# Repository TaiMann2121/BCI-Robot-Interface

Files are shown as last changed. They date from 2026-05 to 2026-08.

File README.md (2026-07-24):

# BCI Robot Interface

An integrated brain-computer interface (BCI) controlled robotic arm and hand system developed in the He Lab. BCI2000 decodes neural signals and streams control outputs to a Kinova Gen3 robotic arm and an Allegro Hand V4, enabling real-time robotic control from brain activity.

## System Overview

The piano task streams all control data as a single combined record on one
BCI2000 UDP port (5005) at 8 Hz. A dispatcher owns that port and fans the record
out to the two controllers:

```
BCI2000 (Windows)
  └── UDP 5005 → bci2000_dispatcher.py ┬── UDP 5006 → arm_controller.py → Kortex API → Kinova Gen3 Arm
                                        └── UDP 5007 → myAllegroHand.exe → PCAN-USB   → Allegro Hand V4
```

The keyboard is a 1-D layout of 11 keys (the middle 7 are notes C–B). The arm
slides horizontally along the keys to track `ArmPred_X`; the hand taps one of
three fingers (`CopilotFingerPred` = left/center/right) when `FingerMovePhase`
pulses. See [docs/setup_guide.md](docs/setup_guide.md) for the packet format and
calibration.

## Repository Structure

```
BCI_RobotInterface/
├── arm/                    Kinova Gen3 arm controller (Python)
├── hand/                   Allegro Hand V4 controller (C++ Visual Studio project)
├── dispatcher/            Single-port stream splitter (Python)
├── simulator/              Piano-stream simulator for testing without BCI2000
├── BCI2000 Piano/         Piano-task BCI2000 files (bat, prm, app module) for reference
└── docs/
    └── setup_guide.md      Full installation and configuration guide
```

## Getting Started

See [docs/setup_guide.md](docs/setup_guide.md) for complete setup instructions including hardware requirements, network configuration, software installation, and build steps.

For testing without BCI2000, run `dispatcher/bci2000_dispatcher.py` alongside
`simulator/bci_arm_hand_simulator.py` — the simulator replicates the real piano
stream (single port, 8 Hz, BCI2000 watch-packet framing) and lets you drive arm
positions and finger presses interactively.

For real experiments, launch BCI2000 with `BCI2000 Piano/SigGen_Piano_vel.bat`.

## Hardware

- Kinova Gen3 robotic arm (connected via Ethernet at `192.168.1.10`)
- Allegro Hand V4 — right hand configuration
- PEAK PCAN-USB CAN adapter

## Contact

He Lab — please reach out to the lab with any questions about this project.

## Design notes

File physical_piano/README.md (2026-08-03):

# Physical Piano — Start Here

Building a real 11-key piano to replace the toy playmat in the BCI arm/hand
piano task.

**Status:** design complete and verified against both the physical rig and the
switch datasheet. Nothing has been bought or fabricated yet.

## Layout

```
docs/       specifications and plans (Markdown — the source of truth)
share/      the same docs as .docx, for the shared Drive folder
cad/        OpenSCAD models
firmware/   Arduino sketch — key scanner only, makes no sound
pc/         computer-side listener that plays the notes
tools/      scripts that generate share/*.docx from docs/*.md
```

### Documents

| File | What it's for |
|---|---|
| [docs/SUPERVISOR_BRIEF.md](docs/SUPERVISOR_BRIEF.md) | **One page + the 4 decisions needed** — for the supervisor meeting |
| [docs/BUILD.md](docs/BUILD.md) | The spec: dimensions, sound, measured forces, mechanism |
| [docs/PURCHASING.md](docs/PURCHASING.md) | What to buy, with links and budget (~$457) |
| [docs/TECHSPARK_PLAN.md](docs/TECHSPARK_PLAN.md) | Fabrication plan + **parts manifest** |
| [docs/datasheets/](docs/datasheets/) | Kailh switch datasheet — the source for every switch dimension |

### CAD — four files, split by role

| File | Contains | Used by |
|---|---|---|
| [cad/piano_params.scad](cad/piano_params.scad) | **Single source of truth.** Every shared dimension and all sanity checks. Edit *here*. | everything |
| [cad/piano_keys.scad](cad/piano_keys.scad) | Key levers + black keys — **printed in both routes** | both |
| [cad/piano_base_printed.scad](cad/piano_base_printed.scad) | All-printed base (cells, 3 tiles) | route A |
| [cad/piano_base_laser.scad](cad/piano_base_laser.scad) | Laser base (2 sheets + stop rail) + 12 printed brackets | route B |
| [cad/piano_frame.scad](cad/piano_frame.scad) | Cosmetic surround — cheeks and rails. Purely aesthetic, print last | either |

> The two `base_*` files are **alternatives — build one, not both.** Either way
> you also need `piano_keys.scad`. Full breakdown in the TechSpark plan's parts
> manifest.

### Regenerating the .docx

```bash
node tools/md2docx.js docs/BUILD.md share/Physical_Piano_Build_Spec.docx
node tools/build_bom_docx.js          # the BOM, which has a custom layout
```

---

## What to do next, in order

### ① Right now (~1 hour, unblocks everything)

1. ~~Measure where the fingertips land on a key.~~ ✅ **35 mm from the front
   edge**, well inside the 53.2 mm clear zone — no black-key collision.
2. **Email TechSpark to book the consult** — Jen Hitchcock,
   jhitchco@andrew.cmu.edu. Lead time, so start early.
3. **Order the electronics** (~$100 — Arduino, MX switches, piezo, wire). They
   get bench-tested while the mechanical side is still in progress.

### ② Verify the CAD

4. Install [OpenSCAD](https://openscad.org) (free) and open each of the four
   `cad/*.scad` files. The console prints the derived geometry and will warn if
   anything is inconsistent. **Nothing has been rendered yet** — confirm the
   shapes look right before committing to fabrication.

### ③ TechSpark

5. Attend the consult — bring the questions in the TechSpark plan. The critical
   ones are laser bed size, 1.5 mm stock availability, and what laser time costs.
6. **Fabricate ONE key + base + black key and test it on the rig.** Do not batch
   11 until that passes.

### ④ Build

7. Full run: 11 keys, 7 black keys, and the base for whichever route was chosen.
8. Wire the 18 switches, flash the firmware, then run
   `python pc/piano_listener.py --port COMx`. Check audio first with
   `--test`, which needs no hardware.
9. Raise the arm ~5–8 mm so resting fingertips hover 2–5 mm above the key tops.
10. Re-run the demo sequence to validate.

---

## Two tracks run in parallel

- **Electronics** — breadboard the Arduino, switches and piezo; test the
  firmware and tuner with no mechanical parts at all.
- **Mechanical** — the slow track, gated by the TechSpark consult.

Start the electronics early so that half is proven before any key exists.

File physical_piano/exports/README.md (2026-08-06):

# Exports — generated files for TechSpark

**These are generated.** The source of truth is `../cad/*.scad`. They are
committed anyway so that a fresh `git clone` on any machine — a laptop taken to
the consult, or TechSpark's own PC — has everything needed to quote and cut,
without needing OpenSCAD installed first.

Regenerate any of them with:

```bash
openscad -o <output> -D 'mode="<mode>"' <source>.scad
```

Do not hand-edit anything here. If a dimension changes, change it in
`../cad/piano_params.scad` and re-export.

---

## Make these FIRST

| File | Process | Stock | Why |
|---|---|---|-----|
| `COUPON_print_switch_holes.stl` | FDM | PLA | 7 holes, 13.8–14.4 mm |
| `COUPON_laser_switch_holes_1.5mm.dxf` | laser | **1.5 mm** | same range, same stock as the real switch plate |

The switch datasheet specifies the plate cutout as 14.00 ±0.05 mm, which
neither process holds natively — FDM undersizes holes, laser kerf oversizes
them. Clip a real switch into each hole, take the smallest one it enters
without force and cannot be pulled out of, and set `mx_cut` from it.

Nothing else should be cut in quantity until that number is known.

---

## Laser route — 3 sheets

Sheet size is **565 × 174 mm** (this is the cut part; 545 mm is the keyboard
width alone, which is *not* the number to check a bed against).

| File | Stock | Qty |
|---|---|----:|
| `LASER_1_structure_9.0mm.dxf` | 9.0 mm | 1 |
| `LASER_2_switchplate_1.5mm.dxf` | **1.5 mm — mandatory**, this is what the MX clips grip | 1 |
| `LASER_3_stoprail_13.0mm.dxf` | 13.0 mm | 1 |
| `PRINT_hinge_bracket_x12.stl` | printed, not lasered | 12 |

The laser route also needs 6 × M3 12 mm standoffs (not yet ordered) and one
continuous 3 mm rod ≥ 581 mm.

## Printed route — 3 tiles

| File | Qty | Notes |
|---|----:|---|
| `PRINT_base_tile_0.stl` | 1 | cells 0–4, 250 mm |
| `PRINT_base_tile_1.stl` | 1 | cells 5–8, 200 mm |
| `PRINT_base_tile_2.stl` | 1 | cells 9–10, 100 mm |

The 5 + 4 + 2 split is not arbitrary — it is the only 3-way split that keeps
both seams off a black-key boundary, where a glue joint would run through a
switch's mounting hole.

## Both routes

| File | Qty | Notes |
|---|----:|---|
| `PRINT_key_lever_x11.stl` | 11 | **~20% infill — this is functional.** The switch guarantees only 15 gf of return force, so a key over 24 g presses its own switch and self-triggers. A solid print is ~41 g. |
| `PRINT_black_key_x7.stl` | 7 | |

---

## Not validated against hardware yet

These reflect the CAD as of the export date. `mx_cut` is still the datasheet
nominal, and two black-key dimensions (`mx_well_w`, `mx_shoulder_w`) are scaled
off a drawing rather than measured. See `../docs/BUILD.md` → "Open items".

Fine for quoting and for the coupon. **Not** to be run in quantity yet.

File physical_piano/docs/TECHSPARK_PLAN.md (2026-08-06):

# Plan for Working with CMU TechSpark

How we get the physical piano's mechanical parts made. Based on the TechSpark
services page: <https://engineering.cmu.edu/techspark/facilities/services.html>

---

## What TechSpark offers us

**3D printers**

| Printer | Process / material | Build volume | Min feature |
|---|---|---|---|
| Bambu X1C | FDM, PLA | 10 × 10 × 10″ (254 mm) | 0.4 mm |
| Stratasys F170 | FDM, ABS + **soluble support** | 10 × 10 × 10″ | 0.4 mm |
| Formlabs Form 3 | SLA resin (listed as coming soon) | 14.5 × 14.5 × 19.3 cm | 85 µm |

**Materials & pricing:** PLA **$0.64/g** · ABS **$1.03/g** · resin **$1.08/g**

**Also available:** machining, fabrication, welding, CNC, **laser cutting**, and
CAD/file-prep help from staff.
Professional services $65/hr + machining $72/hr or fabrication $74/hr.

**File formats accepted:** `.stl` `.obj` `.3mf` `.zip`

**How jobs are submitted:** through the **FBS system** at <https://cmu.fbs.io/>,
after an in-person consult at **Hamerschlag Hall C124**. Billing is via a CMU
oracle string / Andrew HUB account.

**Contacts**
- 3D printing & fabrication — **Jen Hitchcock**, jhitchco@andrew.cmu.edu
- Machining — **Ed Wojciechowski**, wojo@andrew.cmu.edu

---

## The one hard constraint this creates

**The keyboard is 545 mm wide; the build volume is 254 mm.** The keybed cannot
be printed as one piece. The CAD is already designed around this: the base is
built from **tileable 50 mm cells**, so we print it in runs and join them.

- 5 cells per tile = 250 mm → fits the 254 mm bed with 4 mm to spare.
- 11 keys = **3 tiles** (5 + 4 + 2 = cells 0-4, 5-8, 9-10), joined with M3
  hardware. The split is **not** free: the black keys' switch sockets straddle
  the white-key boundaries, so a seam must not land on one or the glue joint
  would run through the 14 mm hole the MX clips grip. Black keys sit after
  cells 0, 2, 3, 5, 6, 7 and 9, so only "after 4" and "after 8" are seam-safe,
  and with a 5-cell tile limit that is the only 3-way split that works.
  (5 + 5 + 1 put a seam after cell 9, which *is* a black-key boundary.)
- Individual white keys (140 × 45 mm) and black keys (87 × 26 mm) fit easily and
  can be batched many-per-plate.

---

## Proposed plan

### Phase 1 — Consult (before printing anything)
Go to **HH C124** and talk to Jen Hitchcock. Bring the CAD and these questions:

1. **Tolerances for moving parts.** There are exactly two moving fits in this
   design, and both are **0.4 mm** — which is also the X1C's stated *minimum
   feature*, so we are sitting on the machine's limit with no margin:

   - **Key side to hinge post, 0.4 mm gap.** The key pivots between two fixed
     posts standing in the 5 mm inter-key gap. Too tight and it rubs or jams
     through its swing; too loose and it wanders sideways on the pin.
   - **Pin bore to rod, 3.4 mm bore on a 3 mm rod.** 0.2 mm all round. This is
     the actual bearing — it is what lets the key rotate without slop.

   Ask: is 0.4 mm realistic in PLA on the X1C, or should we open it up? If the
   answer is open it up, that is a one-line change to `clr` / `pin_d` in
   `piano_params.scad` and a re-export, not a redesign.

   Worth asking in the same breath: the printed hinge post is a **2 mm thick
   fin, 25 mm tall, with a 3.4 mm hole through it** — a 12:1 aspect ratio in
   the thin direction. Will it print without warping or snapping? It is the
   most fragile part of the printed route.

   *(This is the most important question after the 1.5 mm stock one — the whole
   mechanism depends on the key pivoting freely without slop.)*

   > Earlier revisions of this list said "a pin hinge and a **sliding plunger**
   > with 0.4 mm clearances". The plunger slides in nothing: it is a free
   > standing 4 mm post that presses on the switch stem, with 6.5 mm of air
   > either side of it. That wording dated from a design where it ran in a
   > guide bore, and describing it that way at the consult would get advice
   > about a part that does not exist.
2. **PLA vs. ABS.** PLA is cheapest. The F170's **soluble support** could print
   the hinge better. Is ABS worth the 1.6× material cost here?
3. **Laser-cut the switch plate instead of printing tiles.** ⭐ *Highest-value
   question.* MX switches are plate-mount: they clip into a flat plate with
   14 × 14 mm square holes. Cutting that as **one piece** would:
   - hold all 11 switches at an exact **50 mm pitch with no tile seams** — the
     arm's calibration depends on that pitch, so this removes a real risk, not
     just a cost;
   - likely fit the laser bed in one piece where the 254 mm print bed cannot —
     but note the SHEET is **565 x 174 mm**, not 545. 545 is the keyboard width;
     the cut part adds a 10 mm side margin so the outermost hinge brackets land
     on material. Ask about 565, or a yes here becomes a no later;
   - reduce printed mass from ~502 g to ~275 g (**$321 → ~$176**). Note the
     saving is *modest*, not half: laser machine time is billed hourly and
     isn't quoted on the services page, so net saving is likely **$30–80**.
     **Ask what laser time actually costs** — it decides whether the cost
     argument holds at all. The pitch accuracy above is the real reason.

   A worked layered design already exists at
   [`../cad/piano_base_laser.scad`](../cad/piano_base_laser.scad): **three** flat
   layers — structure **9.0 mm**, switch plate **1.5 mm**, stop rail
   **13.0 mm** — whose thicknesses land the switch plate top at **z = 10.5 mm**
   and the stop top at **z = 23.5 mm**, identical to the printed route, so key
   height and arm height are unchanged either way. Only **12** small hinge
   brackets stay printed, because they need a cross-drilled pin hole a laser
   cannot make. (An earlier version had a fourth "spacer" layer and 22
   brackets; the spacer had no remaining job once the structural layer was
   drilled through under every switch, and there is one bracket per key
   boundary, which is 12.)

   Specifics to confirm: **can the bed take 565 x 174 mm**, and can they supply
   **1.5 mm stock** (the thickness MX switches clip into — this one is
   mandatory, not a preference) plus 9.0 mm and 13.0 mm? If 1.5 mm is too
   flimsy over that span, is a stepped two-layer plate (1.5 mm with 14 mm holes
   over a thicker backing with clearance holes) feasible?

   Also ask about **kerf compensation**: the switch cutout is specified
   14.00 ±0.05 mm and an uncompensated cut comes out ~0.2 mm oversize, which is
   the difference between a switch that clips and one that rattles. See the
   test-coupon step in BUILD.md.
4. **Tile joining.** The base cells carry alignment dowel half-holes at the
   two tile seams, so a seam closes onto a 3 mm rod rather than being butted
   by eye. Worth asking whether they would also glue or pin the seam, since
   the 50 mm key pitch — what the arm is calibrated to — has to survive two
   joins on this route. **This is now the likely route**, so it deserves more
   attention than the laser alternative.
5. Turnaround time and how billing works against our lab's oracle string.

### Phase 2 — Prototype ONE key

**Before this:** cut a hole-size coupon and set `mx_cut` from it, and put
calipers on a real switch for `mx_well_w` / `mx_shoulder_w`. Both are in
BUILD.md → "Open items". A switch that will not clip in makes every other
question on this list unanswerable.

Print **1 white key + 1 base cell + 1 black key** (~$30 of material) —
`mode = "assembly"` in `piano_base_printed.scad` is exactly that trio — and
check:

- Does the switch clip into the plate and stay there when pulled by hand?
- Does the key pivot freely and return cleanly?
- Does the switch actuate before the cap hits the bottom stops?
- Does the cap land on the **stop shoulders**, not on the switch? (Press hard —
  the whole point is that the frame takes the robot's overshoot.)
- Does the black keycap grip its cross, and travel its full 3.6 mm without
  fouling the switch housing?
- Do the robot's fingers land in the **front clear zone** (see below)?
- Is the key-top height reachable by the arm's vertical adjustment?

**Do not batch 11 until this passes.** Tuning a parameter costs one reprint at
this stage and eleven reprints later.

### Phase 3 — Full run
Once the prototype is signed off, submit:
- 11 × white key lever
- 3 × base tile (5 + 4 + 2 cells, with black-key switch sockets at the right
  boundaries)
  *— or the laser-cut plate stack, if consult question 3 is a yes*
- 7 × black key

> ⚠️ **Specify low infill (~20%) on the key levers.** This is a functional
> requirement with a hard number: the switch datasheet guarantees only **15 gf**
> of return force, so the **maximum safe key mass is 24 g**. A near-solid key at
> ~41 g would press its own switch and self-trigger. At ~20% infill (~16 g) there
> is a 1.5× margin. It is also cheaper, since TechSpark bills by the gram.

### Phase 4 — Assembly & integration
Wire the switches to the Arduino, flash the firmware, tune the tones, then set
the arm height so the resting fingertips hover 2–5 mm above the key tops, and
re-run the demo sequence.

---

## Parts manifest — what is made how

> ⚠️ **The CAD files are split by ROUTE, not by process.** `piano_base_laser.scad`
> is the laser *route* — it still contains one 3D-printed part. And **either route
> needs `piano_keys.scad`**, because the key levers and black keys are printed in
> both. Do not hand over a single file and assume it covers everything.

**Route A — all 3D printed**

| Part | File | `mode` | Process | Qty |
|---|---|---|---|----:|
| Key lever (notched for the black keys) | `piano_keys.scad` | `"key"` | print, PLA ~20% infill | 11 |
| Black key (switched keycap) | `piano_keys.scad` | `"black"` | print | 7 |
| Base tile | `piano_base_printed.scad` | `"tile"`, `tile_i` = 0/1/2 | print | 3 (5+4+2) |
| Frame cheek | `piano_frame.scad` | `"cheek"` | print | 2 |
| Frame front rail segment | `piano_frame.scad` | `"front_seg"` | print | 3 |
| Frame back rail segment | `piano_frame.scad` | `"back_seg"` | print | 3 |
| Hinge pin | — | — | buy 3 mm rod, cut | — |
| Tile alignment dowels | — | — | same 3 mm rod, 4 short pieces | — |

`mx_switch.scad` is **not a part**. It is a to-scale model of the Kailh switch
plus fit checks that place it in the board, so switch clearances can be looked
at instead of argued from numbers. Run its `"white"`, `"black"` and
`"fit_slice"` modes after any change to the socket, stop or keycap geometry.

Feet are printed into every base cell, so this route needs **no standoffs**.

**Route B — laser-cut base** *(the one we're asking about)*

| Part | File | `mode` | Process | Qty |
|---|---|---|---|----:|
| Key lever | `piano_keys.scad` | `"key"` | **print** | 11 |
| Black key | `piano_keys.scad` | `"black"` | **print** | 7 |
| Structure sheet | `piano_base_laser.scad` | `"2d_struct"` | **laser, 9 mm** | 1 |
| Switch plate | `piano_base_laser.scad` | `"2d_switch_plate"` | **laser, 1.5 mm** | 1 |
| Stop rail | `piano_base_laser.scad` | `"2d_stop_rail"` | **laser, 13 mm** | 1 |
| Hinge bracket | `piano_base_laser.scad` | `"hinge_block"` | **print** | 12 |
| Hinge pin | — | — | buy 3 mm rod, ~570 mm | 1 |
| Standoffs | — | — | buy, 12 mm M3 | 6 |

So Route B is **3 laser parts + 30 printed parts**, drawn from **two** files.

## What to send them

- **Laser:** `../cad/piano_base_laser.scad` exported to **DXF** — one file per `2d_*`
  mode (3 files), each tagged with its stock thickness.
- **Print:** STL per part — key lever and black key (`piano_keys.scad`), plus
  either the base tiles (`piano_base_printed.scad`)
  or the hinge bracket (`piano_base_laser.scad`).
- This document, for the manifest, build volumes, and material context.

*OpenSCAD is installed on the lab PC. Open any `cad/*.scad` file, set `mode`,
press F6, then File > Export. TechSpark staff can help with file prep as part of
professional services if needed.*

---

## Design status

✅ **Black-key clearance — resolved.** Black keys occupy the rear 62% of each
key, so fingers must press in the front 53.2 mm. Measured on the rig: the
fingertip lands **35 mm** from the front edge. Comfortably clear, no
repositioning needed.

⏳ **Base construction — still a choice, no longer a rework.** BOTH routes are
now fully modelled: `piano_base_printed.scad` (3 tiles, 5 + 4 + 2 cells) and
`piano_base_laser.scad` (3 flat layers + 12 printed brackets). Picking one is a
decision, not a redesign. The laser route cuts all 11 switch positions in ONE
operation, so the 50 mm pitch the arm is calibrated to has no glued seams to
drift across, and it is far cheaper in material; the printed route needs no
laser. **Confirm laser access and 9.0 / 1.5 / 13.0 mm stock before committing.**
They are alternatives — do not build both.

⏳ **Switch fit — not yet verified against hardware.** Every dimension the CAD
takes from the switch datasheet has been checked line by line, but three things
cannot be settled on paper: whether the switch actually purchased matches the
datasheet, the two stem dimensions the datasheet draws without dimensioning, and
whether the fabrication process holds the 14.00 ±0.05 plate cutout. See
BUILD.md → "Open items". **Nothing should be fabricated in quantity until these
close.**

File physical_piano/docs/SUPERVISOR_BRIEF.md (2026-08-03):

# Physical Piano — Status & Decisions Needed

One-page summary of the physical 11-key piano that replaces the toy playmat in
the BCI arm/hand piano task. Full detail is in the accompanying Build Spec,
Parts to Purchase, and TechSpark Plan documents.

---

## Your three asks — done

| Ask | Status |
|-----|---|
| **Add the black keys** | ✅ 7 black keys added, mirroring the simulator's exact proportions and positions. Decorative (no switches) as agreed. |
| **Links for materials to purchase** | ✅ Full list with links and prices → *Parts to Purchase* |
| **Plan for the machine shop** | ✅ Phased plan built from TechSpark's services page → *TechSpark Plan* |

## Design is complete — every dimension measured on the real rig

| Parameter | Value |
|---|---|
| Keys | 11 white (4.5 × 14 cm) + 7 black, 5.0 cm pitch, 54.5 cm total |
| Switches | MX-style linear, 45 gf actuation |
| Sound | Arduino tones, tunable from a computer, saved to the board |
| Switch spec | Verified against the Kailh datasheet — travel, forces, and clearances all check out |
| Robot press force | 362 / 500 / 520 gf (index / middle / ring) |
| Finger contact point | 35 mm from key front edge — clear of the black keys ✅ |

Firmware and the computer-side tuning tool are already written. Nothing in the
design is now a guess.

---

## What I need from you

### 1. Budget approval
| Option | Cost |
|---|-----:|
| All 3D printed | **~$457** |
| With a laser-cut base (see #2) | **~$295 + laser machine time** |

Electronics are only ~$100 of either. I'd like to order those **now** so I can
build and test the whole sound system on a breadboard while the mechanical parts
are still being made — the two halves are independent.

### 2. Laser-cut the base instead of 3D printing it?
I'd like to ask TechSpark about this. **The reason is accuracy, not cost.** The
keybed needs 11 switch holes at an exact 50 mm pitch, which is what the robot
arm is calibrated to. 3D printing means joining 3 separate tiles (the printers
are only 10″ wide), so the pitch has to survive two seams. Laser-cutting the
plate as one piece removes that risk entirely — and it's how these switches are
normally mounted.

I've drafted the layered version so both options are costed on the same basis.
On money it's a **modest** win, not a dramatic one: printed mass drops from
~502 g to ~275 g, but laser machine time is billed hourly and isn't published,
so the net saving is probably $40–90. I'll get a real number at the consult.

### 3. Funding account
TechSpark bills to a CMU oracle string. Which account should I use, and should I
place the material orders myself or send them to you?

### 4. Confirm the sound is what you pictured
You asked for electronic sound tunable on a computer, which is what I built: I
can set **each key's pitch** live over USB and save it. But the tone is always a
square-wave "beep" — the *timbre* can't be reshaped from the computer. If you
pictured adjusting the character of the sound (or wanted realistic piano
samples), that's a different setup and I'd rather find out now than after the
board is built.

---

## Two findings worth knowing

- **The arm needs to rise slightly.** The finished keyboard stands on 12 mm
  feet so the switch pins and wiring clear the desk, putting the key tops
  42.5 mm above the table. The fingers currently rest at 40 mm, so the arm
  goes up about 5–8 mm. Well within its adjustment range.
- **Keys must be printed at low infill — there's a hard limit.** The switch
  datasheet guarantees only 15 gf of return force, so a key must weigh under
  **24 g**. Ours is ~16 g at normal infill; printed near-solid it would be ~41 g
  and would sag onto its own switch and self-trigger. Cheaper too, since
  TechSpark bills by the gram.

## Next steps once approved

1. Book the TechSpark consult (Jen Hitchcock) — has lead time, so I'd start now
2. Order the electronics (~$100) and bench-test the sound
3. **Print one key and test it on the robot** before committing to all 11
4. Full print run → assemble → re-run the demo on the real keyboard

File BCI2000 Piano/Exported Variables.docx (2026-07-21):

CurrentTrial - block number 1-5

InnerTrialCount - trial number 0-

ArmPred_X - real-time robotic arm position with an offset of 32767; value should be within [-420, 420]

FingerMovePhase - indicate the timing of the finger motion; finger move when value turns True

CopilotFingerPred - finger prediction; 0, 1, 2

targetKeyIndex - target key [2, 8]

pressedKeyIndex - pressed key [0, 10]

ArmCurrentIndex - reflect the current arm position in terms of the key index (which key the middle finger is on) [1, 9]

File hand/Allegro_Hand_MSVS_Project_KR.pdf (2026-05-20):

# Allegro Hand Programming Tutorial

# Allegro Hand Console Application

# Allegro Hand 2.0

Copyright 2013 SimLab Co., Ltd. All rights reserved.

# - Creating a new project

# - CAN implementation

# - Monitoring joint angles using rPanelManipulator

# - Control Allegro Hand using BHand library

# - Source code

# ■ Creating a new project

1. Visual Studio 2008 실행한다.
2. “File > New > Project” 메뉴를 이용하여 새 프로젝트를 생성한다.
3. Win32 Console Application을 선택하고 프로젝트 이름에 myAllegroHand 라고 입력한다.

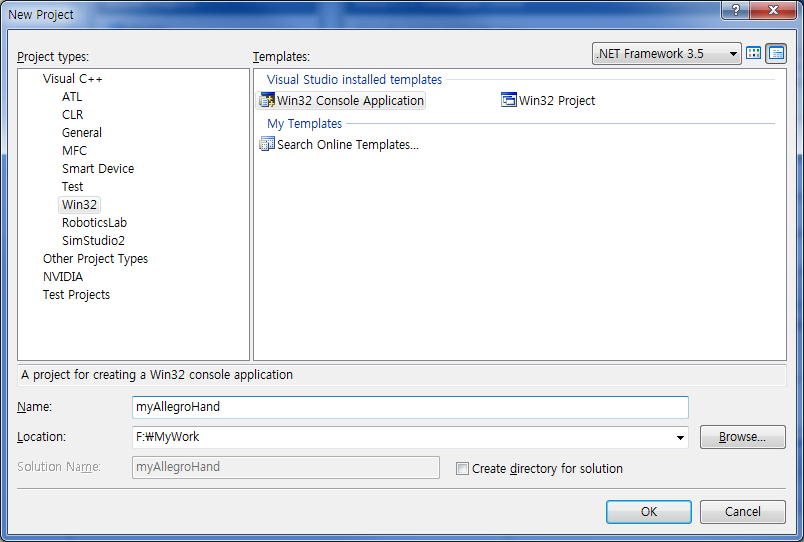
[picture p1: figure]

4. Application type에 “Console application”을 선택한 후 “Finish” 버튼을 눌러 완료한다.

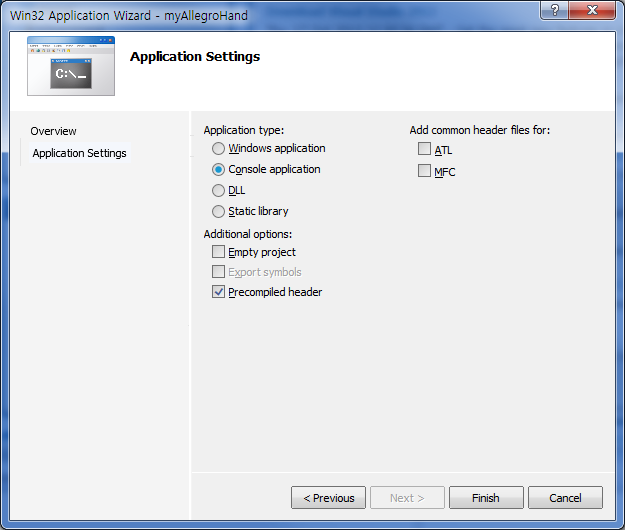
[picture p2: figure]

# 5. 프로젝트가 정상적으로 생성되었다면 CAN 통신 등을 위해 미리 작성된 파일들을 프로젝트가

# 생성된 폴더에 덮어쓴다. 그리고 프로젝트에 필요한 파일들을 추가한다. 다음은 필요 파일들을

추가한 후 솔루션 탐색기 모습이다. 프로젝트 생성시 자동 생성된 “stdafx.h”, “targetver.h”, “myAllegroHand.cpp”, “sdafx.cpp”, “ReadMe.txt” 외에 “canAPI.h”, “canDef.h”, PCANBasic.h”,

# “rDeviceAllegroHandCANDef.h”, “canAPI.cpp” 파일이 추가되어있다. 이 때 한가지 주의해야 할 점

# 은 CAN 장치 제조사마다 “canAPI.cpp” 파일을 같은 이름으로 하나씩 제공하고 있기 때문에 사

# 용하려고 하는 CAN 장치에 따라 알맞은 파일을 선택해야 한다는 것이다. 본 튜토리얼은 Peak

CAN | 장치를 | 사용하는 | 것을 | 가정하고 | 있다. | 때문에 | “canAPI.cpp” | 파일 | 추가시
“src\Peak\canAPI.cpp” 파일을 선택하여 프로젝트에 추가하였다.

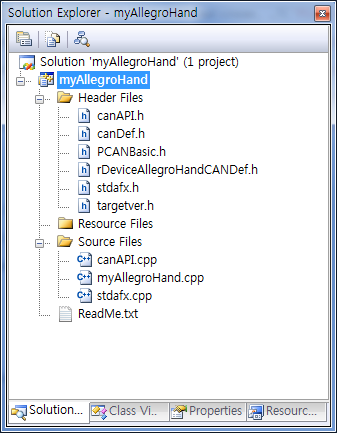
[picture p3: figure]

# 6. 프로젝트 설정 다이얼로그를 열기 위해 솔루션 탐색기에서 프로젝트를 선택한 후 마우스 우클

# 릭, 그리고 속성 메뉴를 선택한다. 프로젝트 설정 다이얼로그에서 다음과 같이 “Create/Use

Precompiled Header” 속성을 “Not Using Precompiled Headers”로 변경한다.

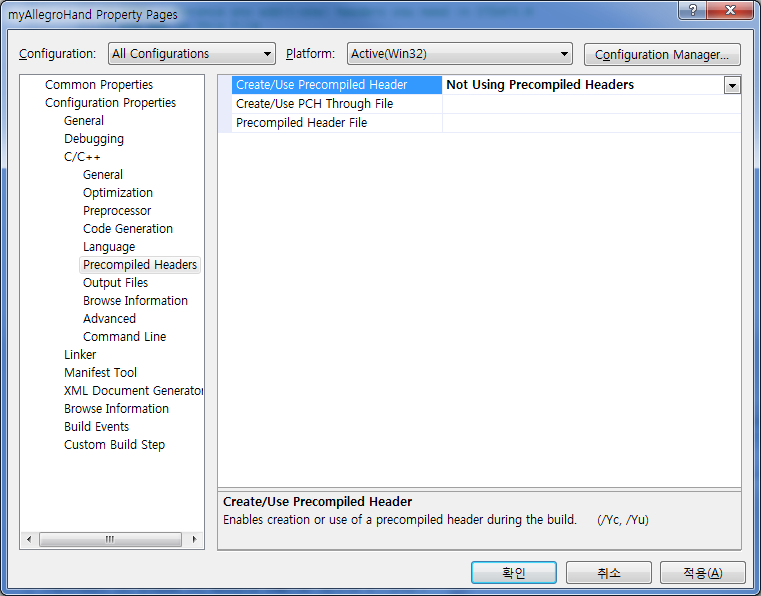
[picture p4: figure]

7. “Additional Include Directories”에 “include”를 추가한다.

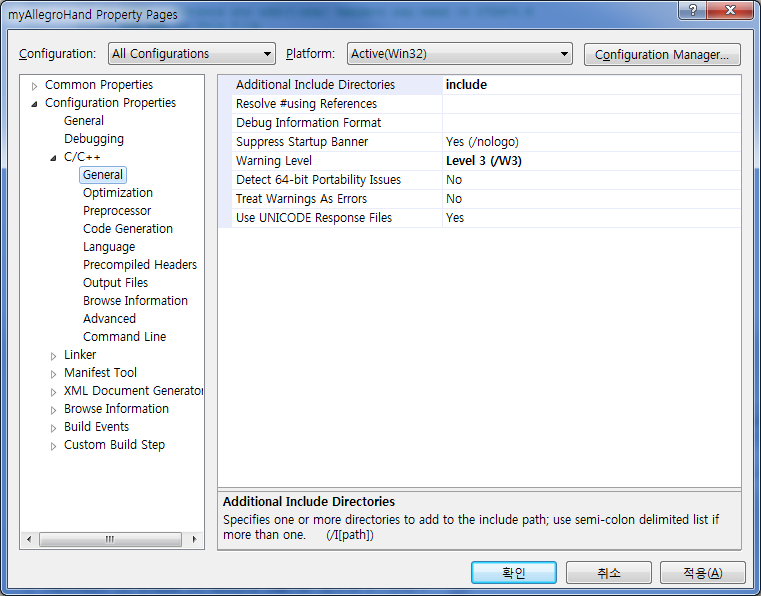
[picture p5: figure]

# 8. “Additional Library Directories”에 “lib\Peak”를 추가한다. 본 튜토리얼은 Peak CAN 장치를 이용

# 하는 것을 가정하고 있다. 만약 Peak CAN 이외의 다른 CAN 장치를 이용하는 경우 lib 폴더에서

# 해당 장치 제조사 이름의 폴더를 찾아 그 이름을 설정하도록 한다. 현재 Allegro Hand는 “ESD-

CAN”, “Kvaser”, “NI-CAN”, “Peak”, “Softing” CAN 장치를 지원한다.

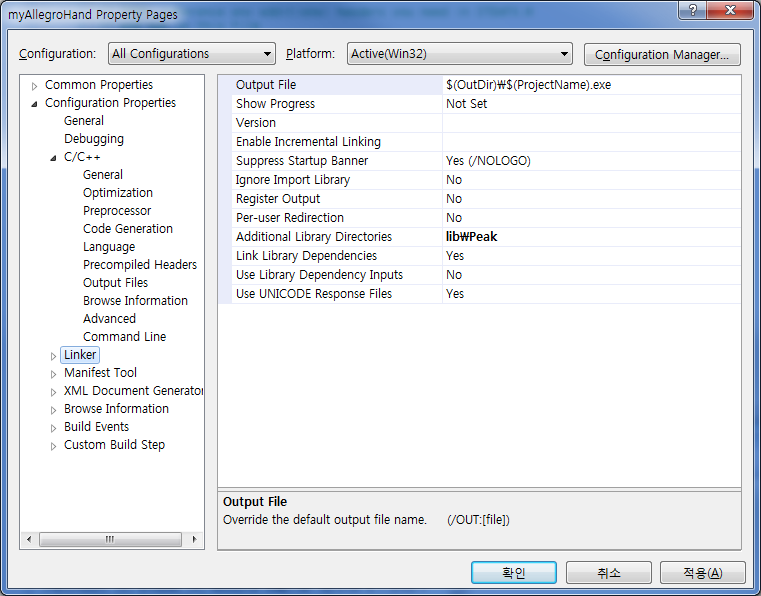
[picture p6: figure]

9. “Additional Dependancies”에 “PCANBasic.lib”을 추가한다.

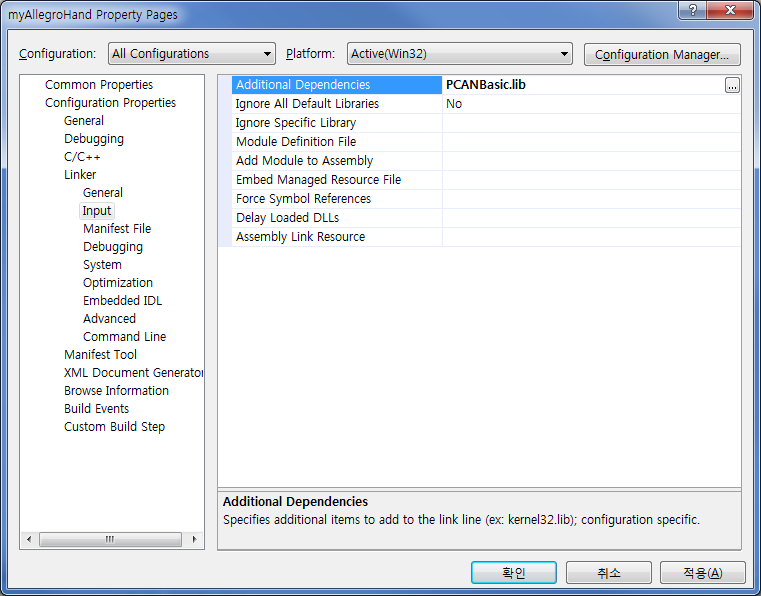
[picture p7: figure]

10. 실행 경로를 “bin”으로 설정한다.

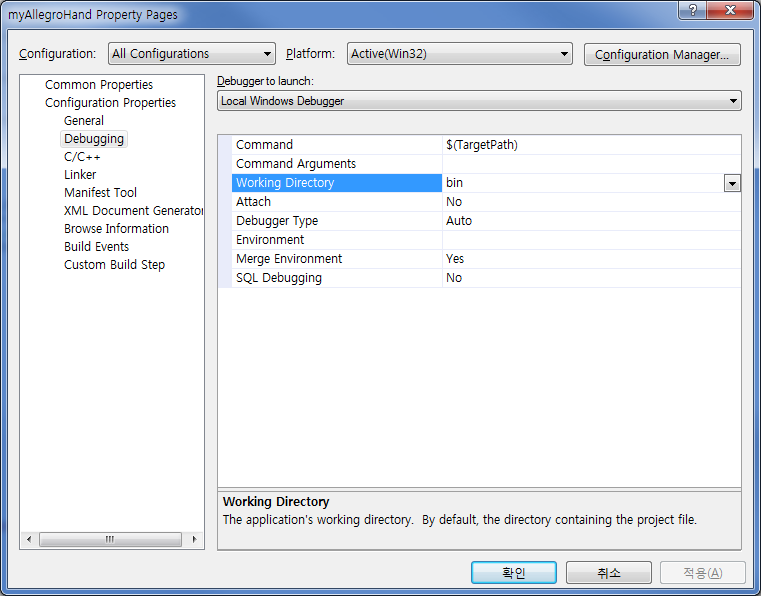
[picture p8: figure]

# ■ CAN implementation

11. 이제 myAllegroHand.cpp 파일을 연다. 먼저 필요한 헤더 파일을 추가한다.

#include "stdafx.h"

#include "windows.h"

#include <conio.h>

#include <process.h>

#include <tchar.h>

#include "canAPI.h"

#include "rDeviceAllegroHandCANDef.h"

# 12. CAN 통신을 위한 전역변수를 선언한다. “CAN_Ch” 변수는 CAN 통신 채널을 위한 인덱스를 저

# 장하기 위한 변수이다. “vars” 변수는 CAN 통신을 통해 수신된 각 관절 엔코더값 및 각 관절에

인가할 토크 명령을 저장한다.

int CAN_Ch = 0;
bool ioThreadRun = false;
uintptr_t ioThread = 0;
int recvNum = 0;
int sendNum = 0;
double statTime = -1.0;
double curTime = 0.0;
AllegroHand_DeviceMemory_t vars;

# 13. “main” 함수를 다음과 같이 편집한다. Main 함수는 크게 네가지 함수로 구성된다. 다음에 각 함

수에 대해 설명한다.

int _tmain(int argc, _TCHAR* argv[])
{
PrintInstruction();

if (OpenCAN())
{
MainLoop();
CloseCAN();
}

return 0;
};

# 14. “PrintInstruction()” 함수는 프로그램 정보 및 실행 방법 등을 콘솔에 출력하는 함수이다. 구현은

다음과 같다.

void PrintInstruction()
{
printf("--------------------------------------------------\n"); printf("myAllegroHand\n");
printf("\n");
printf("To quit this program, press 'q'.\n");
printf("--------------------------------------------------\n");
}

# 15. “OpenCAN()” 함수는 CAN 통신을 초기화하고 CAN을 통해 데이터 수신 및 송신을 위한 별도의

# 쓰레드(thread)를 생성한다. 그리고 Allegro Hand 시스템을 초기화하고 제어를 위해 주기적 통신

을 시작한다.

bool OpenCAN()
{
int ret;

CAN_Ch = GetCANChannelIndex(_T("USBBUS1"));

printf(">CAN(%d): open\n", CAN_Ch);
ret = command_can_open(CAN_Ch);
if(ret < 0)
{
printf("ERROR command_canopen !!! \n"); return false;
}

memset(&vars, 0, sizeof(vars)); recvNum = 0;
sendNum = 0;
statTime = 0.0;

ioThreadRun = true;
ioThread = _beginthreadex(NULL, 0, ioThreadProc, NULL, 0, NULL); printf(">CAN: starts listening CAN frames\n");

printf(">CAN: system init\n");
ret = command_can_sys_init(CAN_Ch, 3/*msec*/); if(ret < 0)
{
printf("ERROR command_can_sys_init !!! \n"); command_can_close(CAN_Ch);
return false;
}

printf(">CAN: start periodic communication\n"); ret = command_can_start(CAN_Ch);
if(ret < 0)
{
printf("ERROR command_can_start !!! \n"); command_can_stop(CAN_Ch);
command_can_close(CAN_Ch);
return false;
}

return true;
}
16. “CloseCAN()” 함수는 통신 쓰레드 및 CAN 통신을 종료한다.

void CloseCAN()
{
int ret;

printf(">CAN: stop periodic communication\n"); ret = command_can_stop(CAN_Ch);
if(ret < 0)
{
printf("ERROR command_can_stop !!! \n"); }

printf(">CAN: stoped listening CAN frames\n"); ioThreadRun = false;
WaitForSingleObject((HANDLE)ioThread, INFINITE); CloseHandle((HANDLE)ioThread);
ioThread = 0;

printf(">CAN(%d): close\n", CAN_Ch);
ret = command_can_close(CAN_Ch);
if(ret < 0) printf("ERROR command_can_close !!! \n");
}
17. 그 외 중요 함수로 “ioThreadProc” 함수가 있다. 이는 CAN 통신을 처리하는 쓰레드 핸들러이다. Allegro Hand는 3msec마다 모든 관절의 엔코더값을 4개의 CAN frame에 실어 PC로 전송하는데, 4개의 CAN frame을 모두 받으면 계산된 관절 토크를 Allegro Hand로 전송한다.

static unsigned int __stdcall ioThreadProc(void* inst)
{
char id_des;
char id_cmd;
char id_src;
int len;
unsigned char data[8];
unsigned char data_return = 0;

while (ioThreadRun)
{
while (0 == get_message(CAN_Ch, &id_cmd, &id_src, &id_des, &len, data, FALSE)) {
switch (id_cmd)
{
case ID_CMD_QUERY_CONTROL_DATA: {
if (id_src >= ID_DEVICE_SUB_01 && id_src <= ID_DEVICE_SUB_04)
{
vars.enc_actual[(id_src-ID_DEVICE_SUB_01)*4 + 0] = (int)(data[0] | (data[1] << 8));
vars.enc_actual[(id_src-ID_DEVICE_SUB_01)*4 + 1] = (int)(data[2] | (data[3] << 8));
vars.enc_actual[(id_src-ID_DEVICE_SUB_01)*4 + 2] = (int)(data[4] | (data[5] << 8));
vars.enc_actual[(id_src-ID_DEVICE_SUB_01)*4 + 3] = (int)(data[6] | (data[7] << 8));
data_return |= (0x01 << (id_src-ID_DEVICE_SUB_01));
recvNum++;
}
if (data_return == (0x01 | 0x02 | 0x04 | 0x08))
{
// send torques
for (int i=0; i<4;i++)
{
write_current(CAN_Ch, i, &vars.pwm_demand[4*i]); for(int k=0; k<100000; k++);
}
sendNum++;
data_return = 0;
}
}
break;
}
}
}

return 0;
}

# 18. “GetCANChannelIndex()” 함수는 Peak CAN에서 사용하기 위한 함수로 Peak CAN이 지원하는 포

# 트 이름을 입력하여 그에 상응하는 인덱스를 리턴한다. “CAN_Ch” 변수를 초기화하기 위해 사용

된다.
19. 다음은 전체 소스이다.

// myAllegroHand.cpp : Defines the entry point for the console application. //

#include "stdafx.h"

#include "windows.h"

#include <conio.h>

#include <process.h>

#include <tchar.h>

#include "canAPI.h"

#include "rDeviceAllegroHandCANDef.h"

int CAN_Ch = 0;
bool ioThreadRun = false;
uintptr_t ioThread = 0;
int recvNum = 0;
int sendNum = 0;
double statTime = -1.0;
AllegroHand_DeviceMemory_t vars;

void PrintInstruction();
void MainLoop();
bool OpenCAN();
void CloseCAN();
int GetCANChannelIndex(const TCHAR* cname);

static unsigned int __stdcall ioThreadProc(void* inst) {
char id_des;
char id_cmd;
char id_src;
int len;
unsigned char data[8];
unsigned char data_return = 0;

while (ioThreadRun)
{
while (0 == get_message(CAN_Ch, &id_cmd, &id_src, &id_des, &len, data, FALSE)) {
switch (id_cmd)
{
case ID_CMD_QUERY_CONTROL_DATA: {
if (id_src >= ID_DEVICE_SUB_01 && id_src <= ID_DEVICE_SUB_04)
{
vars.enc_actual[(id_src-ID_DEVICE_SUB_01)*4 + 0] = (int)(data[0] | (data[1] << 8));
vars.enc_actual[(id_src-ID_DEVICE_SUB_01)*4 + 1] = (int)(data[2] | (data[3] << 8));
vars.enc_actual[(id_src-ID_DEVICE_SUB_01)*4 + 2] = (int)(data[4] | (data[5] << 8));
vars.enc_actual[(id_src-ID_DEVICE_SUB_01)*4 + 3] = (int)(data[6] | (data[7] << 8));
data_return |= (0x01 << (id_src-ID_DEVICE_SUB_01));
recvNum++;
}
if (data_return == (0x01 | 0x02 | 0x04 | 0x08))
{
// send torques
for (int i=0; i<4;i++)
{
write_current(CAN_Ch, i, &vars.pwm_demand[4*i]); for(int k=0; k<100000; k++);
}
sendNum++;
data_return = 0;
}
}
break;
}
}
}

return 0;
}

void MainLoop()
{
bool bRun = true;
int i;

while (bRun)
{
if (!_kbhit())
{
Sleep(5);
}
else
{
int c = _getch();
switch (c)
{
case 'q':
bRun = false;
break;
}
}
}

}

bool OpenCAN()
{
int ret;

CAN_Ch = GetCANChannelIndex(_T("USBBUS1"));

printf(">CAN(%d): open\n", CAN_Ch);
ret = command_can_open(CAN_Ch);
if(ret < 0)
{
printf("ERROR command_canopen !!! \n"); return false;
}

memset(&vars, 0, sizeof(vars)); recvNum = 0;
sendNum = 0;
statTime = 0.0;

ioThreadRun = true;
ioThread = _beginthreadex(NULL, 0, ioThreadProc, NULL, 0, NULL); printf(">CAN: starts listening CAN frames\n");

printf(">CAN: system init\n");
ret = command_can_sys_init(CAN_Ch, 3/*msec*/); if(ret < 0)
{
printf("ERROR command_can_sys_init !!! \n"); command_can_close(CAN_Ch);
return false;
}

printf(">CAN: start periodic communication\n"); ret = command_can_start(CAN_Ch);
if(ret < 0)
{
printf("ERROR command_can_start !!! \n"); command_can_stop(CAN_Ch);
command_can_close(CAN_Ch);
return false;
}

return true;
}

void CloseCAN()
{
int ret;

printf(">CAN: stop periodic communication\n"); ret = command_can_stop(CAN_Ch);
if(ret < 0)
{
printf("ERROR command_can_stop !!! \n"); }

printf(">CAN: stoped listening CAN frames\n"); ioThreadRun = false;
WaitForSingleObject((HANDLE)ioThread, INFINITE); CloseHandle((HANDLE)ioThread);
ioThread = 0;

printf(">CAN(%d): close\n", CAN_Ch);
ret = command_can_close(CAN_Ch);
if(ret < 0) printf("ERROR command_can_close !!! \n"); }

void PrintInstruction()
{
printf("--------------------------------------------------\n"); printf("myAllegroHand\n");
printf("\n");
printf("To quit this program, press 'q'.\n"); printf("--------------------------------------------------\n"); }

int GetCANChannelIndex(const TCHAR* cname)
{
if (!cname) return 0;

if (!_tcsicmp(cname, _T("0")) || !_tcsicmp(cname, _T("PCAN_NONEBUS")) || !_tcsicmp(cname, _T("NONEBUS"))) return 0;
else if (!_tcsicmp(cname, _T("1")) || !_tcsicmp(cname, _T("PCAN_ISABUS1")) || !_tcsicmp(cname, _T("ISABUS1"))) return 1;
else if (!_tcsicmp(cname, _T("2")) || !_tcsicmp(cname, _T("PCAN_ISABUS2")) || !_tcsicmp(cname, _T("ISABUS2"))) return 2;
else if (!_tcsicmp(cname, _T("3")) || !_tcsicmp(cname, _T("PCAN_ISABUS3")) || !_tcsicmp(cname, _T("ISABUS3"))) return 3;
else if (!_tcsicmp(cname, _T("4")) || !_tcsicmp(cname, _T("PCAN_ISABUS4")) || !_tcsicmp(cname, _T("ISABUS4"))) return 4;
else if (!_tcsicmp(cname, _T("5")) || !_tcsicmp(cname, _T("PCAN_ISABUS5")) || !_tcsicmp(cname, _T("ISABUS5"))) return 5;
else if (!_tcsicmp(cname, _T("7")) || !_tcsicmp(cname, _T("PCAN_ISABUS6")) || !_tcsicmp(cname, _T("ISABUS6"))) return 6;
else if (!_tcsicmp(cname, _T("8")) || !_tcsicmp(cname, _T("PCAN_ISABUS7")) || !_tcsicmp(cname, _T("ISABUS7"))) return 7;
else if (!_tcsicmp(cname, _T("8")) || !_tcsicmp(cname, _T("PCAN_ISABUS8")) || !_tcsicmp(cname, _T("ISABUS8")))

return 8;
else if (!_tcsicmp(cname, _T("9")) || !_tcsicmp(cname, _T("PCAN_DNGBUS1")) || !_tcsicmp(cname, _T("DNGBUS1"))) return 9;
else if (!_tcsicmp(cname, _T("10")) || !_tcsicmp(cname, _T("PCAN_PCIBUS1")) || !_tcsicmp(cname, _T("PCIBUS1"))) return 10;
else if (!_tcsicmp(cname, _T("11")) || !_tcsicmp(cname, _T("PCAN_PCIBUS2")) || !_tcsicmp(cname, _T("PCIBUS2"))) return 11;
else if (!_tcsicmp(cname, _T("12")) || !_tcsicmp(cname, _T("PCAN_PCIBUS3")) || !_tcsicmp(cname, _T("PCIBUS3"))) return 12;
else if (!_tcsicmp(cname, _T("13")) || !_tcsicmp(cname, _T("PCAN_PCIBUS4")) || !_tcsicmp(cname, _T("PCIBUS4"))) return 13;
else if (!_tcsicmp(cname, _T("14")) || !_tcsicmp(cname, _T("PCAN_PCIBUS5")) || !_tcsicmp(cname, _T("PCIBUS5"))) return 14;
else if (!_tcsicmp(cname, _T("15")) || !_tcsicmp(cname, _T("PCAN_PCIBUS6")) || !_tcsicmp(cname, _T("PCIBUS6"))) return 15;
else if (!_tcsicmp(cname, _T("16")) || !_tcsicmp(cname, _T("PCAN_PCIBUS7")) || !_tcsicmp(cname, _T("PCIBUS7"))) return 16;
else if (!_tcsicmp(cname, _T("17")) || !_tcsicmp(cname, _T("PCAN_PCIBUS8")) || !_tcsicmp(cname, _T("PCIBUS8"))) return 17;
else if (!_tcsicmp(cname, _T("18")) || !_tcsicmp(cname, _T("PCAN_USBBUS1")) || !_tcsicmp(cname, _T("USBBUS1"))) return 18;
else if (!_tcsicmp(cname, _T("19")) || !_tcsicmp(cname, _T("PCAN_USBBUS2")) || !_tcsicmp(cname, _T("USBBUS2"))) return 19;
else if (!_tcsicmp(cname, _T("20")) || !_tcsicmp(cname, _T("PCAN_USBBUS3")) || !_tcsicmp(cname, _T("USBBUS3"))) return 20;
else if (!_tcsicmp(cname, _T("21")) || !_tcsicmp(cname, _T("PCAN_USBBUS4")) || !_tcsicmp(cname, _T("USBBUS4"))) return 21;
else if (!_tcsicmp(cname, _T("22")) || !_tcsicmp(cname, _T("PCAN_USBBUS5")) || !_tcsicmp(cname, _T("USBBUS5"))) return 22;
else if (!_tcsicmp(cname, _T("23")) || !_tcsicmp(cname, _T("PCAN_USBBUS6")) || !_tcsicmp(cname, _T("USBBUS6"))) return 23;
else if (!_tcsicmp(cname, _T("24")) || !_tcsicmp(cname, _T("PCAN_USBBUS7")) || !_tcsicmp(cname, _T("USBBUS7"))) return 24;
else if (!_tcsicmp(cname, _T("25")) || !_tcsicmp(cname, _T("PCAN_USBBUS8")) || !_tcsicmp(cname, _T("USBBUS8"))) return 25;
else if (!_tcsicmp(cname, _T("26")) || !_tcsicmp(cname, _T("PCAN_PCCBUS1")) || !_tcsicmp(cname, _T("PCCBUS1"))) return 26;
else if (!_tcsicmp(cname, _T("27")) || !_tcsicmp(cname, _T("PCAN_PCCBUS2")) || !_tcsicmp(cname, _T("PCCBUS2"))) return 271;
else
return 0;
}

int _tmain(int argc, _TCHAR* argv[]) {
PrintInstruction();

if (OpenCAN())
{
MainLoop();
CloseCAN();
}

return 0;
}
20. 프로그램을 빌드한다.

# 21. Allegro Hand에 전원을 인가하고 프로그램을 실행한다. 다음과 같은 메시지가 보인다면 프로그

램이 잘 실행되는 것이다.

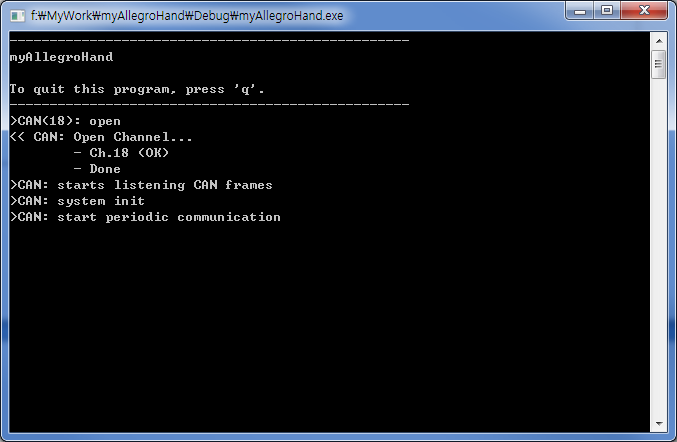
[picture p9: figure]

22. ‘q’ 버튼을 눌러 프로그램을 종료한다.

# ■ Monitoring joint angles using rPanelManipulator

# 23. 실제로 CAN 통신을 통해 엔코더값이 잘 수신되는지 확인하기 위하여 “rPanelManipulator”를 이

용해보자. 이를 위하여 다음과 같이 추가적이 헤더 파일을 인크루드해야 한다.

#include "rPanelManipulatorCmdUtil.h"

24. 전역변수를 선언한다.

rPanelManipulatorData_t* pSHM = NULL;

# 25. “main” 함수에서 “pSHM” 변수를 초기화한다. 그리고 프로그램 종료전 사용을 해지한다. 다음은

수정된 “main” 함수이다.

int _tmain(int argc, _TCHAR* argv[])
{
PrintInstruction();

pSHM = getrPanelManipulatorCmdMemory();

if (OpenCAN())
{
MainLoop();
CloseCAN();
}

closerPanelManipulatorCmdMemory();

return 0;
}

# 26. “MainLoop” 함수에서 엔코더 값을 “rPanelManipulator” 메모리에 복사한다. “MainLoop” 함수를

다음과 같이 변경한다.

void MainLoop()
{
bool bRun = true;
int i;

while (bRun)
{
if (!_kbhit())
{
Sleep(5);
if (pSHM)
{
for (i=0; i<MAX_DOF; i++)
pSHM->state.slave_state[i].position = (double)(vars.enc_actual[i]-32768)*(333.3/65536.0)*(3.141592/180.0); }
}
else
{
int c = _getch();
switch (c)
{
case 'q':
bRun = false;
break;
}
}
}
}
27. 프로그램을 빌드한 후 실행한다.

# 28. “rPanelManipulator” 실행을 위해서 우선 “NTGRAPH.ocx” 를 시스템에 등록해야 한다. 이를 위해

# 서 “Windows Command Shell”을 반드시 관리자 권한으로 실행한다. “NTGRAPH.ocx”는 bin 폴더

# 아래에 있다. 해당 폴더로 이동 후 다음과 같이 “regsvr32 NTGraph.ocx” 명령을 실행하여 등록

한다.

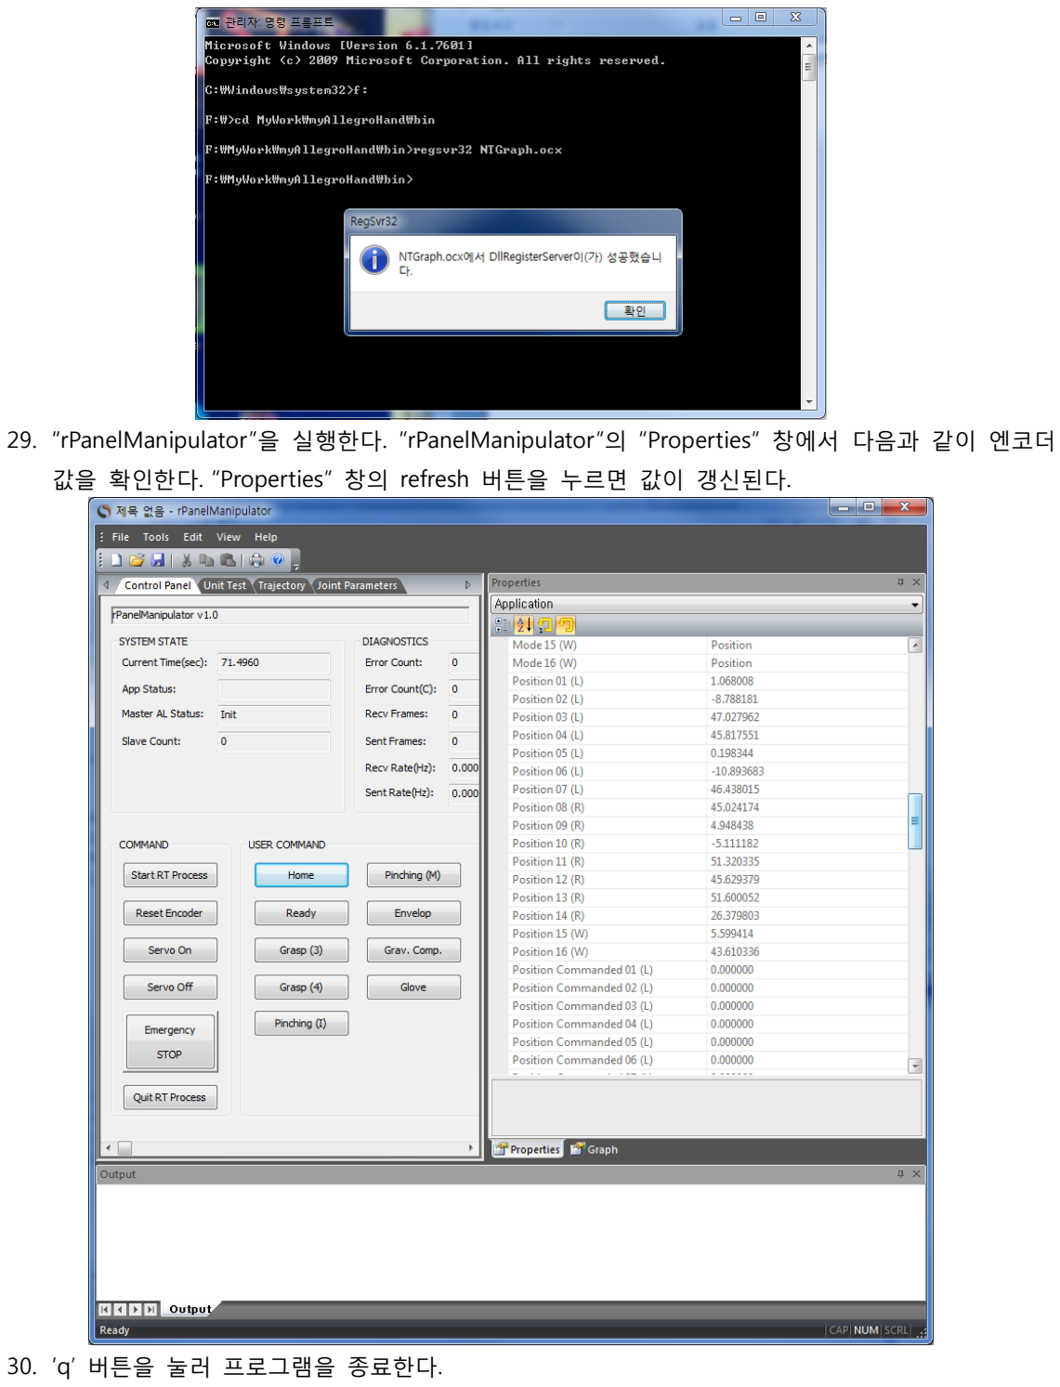
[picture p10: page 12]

# 29. “rPanelManipulator”을 실행한다. “rPanelManipulator”의 “Properties” 창에서 다음과 같이 엔코더

값을 확인한다. “Properties” 창의 refresh 버튼을 누르면 값이 갱신된다.

30. ‘q’ 버튼을 눌러 프로그램을 종료한다.

# ■ Control Allegro Hand using BHand library

# 31. ”BHand” 라이브러리는 Allegro Hand를 위한 다양한 grasping 알고리즘을 제공한다. “BHand” 라

이브러리를 이용하여 Allegro Hand를 제어해보자. 먼저 헤더파일을 인크루드한다.

#include "BHand/BHand.h"

# 32. 전역변수를 선언한다. ”BHand” 인스턴스 포인터인 “pBHand”, 관절각 및 토크 명령, 전류 명령을

# 저장하는 “q”, “tau_des”, “cur_des”, 그리고 엔코더 오프셋 “enc_offset”, 엔코더 방향 “enc_dir”, 모

# 터 방향 “motor_dir” 등을 선언한다. 엔코더 오프셋, 엔코더 방향, 모터 방향은 제품마다 다르므

로 설정시 각 제품에 맞는 값을 설정한다. 이는 Allegro Hand Wiki 에서 얻을 수 있다.

BHand* pBHand = NULL;
double q[MAX_DOF];
double tau_des[MAX_DOF];
double cur_des[MAX_DOF];
const int enc_offset[MAX_DOF] = { // SAH020CR020 -611, -66016, 1161, 1377,
-342, -66033, -481, 303,
30, -65620, 446, 387,
-3942, -626, -65508, -66768
};
const double enc_dir[MAX_DOF] = { // SAH020CR020 1.0, -1.0, 1.0, 1.0,
1.0, -1.0, 1.0, 1.0,
1.0, -1.0, 1.0, 1.0,
1.0, 1.0, -1.0, -1.0
};
const double motor_dir[MAX_DOF] = { // SAH020CR020 1.0, 1.0, 1.0, 1.0,
1.0, -1.0, -1.0, 1.0,
-1.0, 1.0, 1.0, 1.0,
1.0, 1.0, 1.0, 1.0
};
33. 몇 개의 함수를 추가한다. 제일 먼저 “CreateBHandAlgorithm”는 BHand 객체를 생성한다.

bool CreateBHandAlgorithm()
{
pBHand = bhCreateRightHand(); if (!pBHand) return false; pBHand->SetTimeInterval(delT);
return true;
}
34. “DestroyBHandAlgorithm”는 BHand 객체를 삭제한다.

void DestroyBHandAlgorithm()
{
if (pBHand)
{
delete pBHand;
pBHand = NULL;
}
}
35. “ComputeTorque”는 “BHand” 라이브러리를 이용하여 관절 토크를 계산한다.

void ComputeTorque()
{
if (!pBHand) return;
pBHand->SetJointPosition(q); // tell BHand library the current joint positions pBHand->UpdateControl(0);
pBHand->GetJointTorque(tau_des);
}

# 36. “ioThreadProc” 함수는 CAN 통신을 처리하는 쓰레드 핸들러이다. Allegro Hand는 3msec마다 모

# 든 관절의 엔코더값을 4개의 CAN frame에 실어 PC로 전송하는데, 4개의 CAN frame을 모두 받

# 으면 관절 토크를 계산하여 Allegro Hand로 전송한다. 따라서 “ioThreadProc” 함수를 다음과 같

이 변경한다.

static unsigned int __stdcall ioThreadProc(void* inst) {
char id_des;
char id_cmd;
char id_src;
int len;
unsigned char data[8];
unsigned char data_return = 0; int i;

while (ioThreadRun)
{
while (0 == get_message(CAN_Ch, &id_cmd, &id_src, &id_des, &len, data, FALSE)) {

switch (id_cmd)
{
case ID_CMD_QUERY_CONTROL_DATA: {
if (id_src >= ID_DEVICE_SUB_01 && id_src <= ID_DEVICE_SUB_04)
{
vars.enc_actual[(id_src-ID_DEVICE_SUB_01)*4 + 0] = (int)(data[0] | (data[1] << 8));
vars.enc_actual[(id_src-ID_DEVICE_SUB_01)*4 + 1] = (int)(data[2] | (data[3] << 8));
vars.enc_actual[(id_src-ID_DEVICE_SUB_01)*4 + 2] = (int)(data[4] | (data[5] << 8));
vars.enc_actual[(id_src-ID_DEVICE_SUB_01)*4 + 3] = (int)(data[6] | (data[7] << 8));
data_return |= (0x01 << (id_src-ID_DEVICE_SUB_01));
recvNum++;
}
if (data_return == (0x01 | 0x02 | 0x04 | 0x08))
{
// convert encoder count to joint angle for (i=0; i<MAX_DOF; i++)
q[i] = (double)(vars.enc_actual[i]*enc_dir[i]-32768-enc_offset[i])*(333.3/65536.0)*(3.141592/180.0);

// compute joint torque
ComputeTorque();

// convert desired torque to desired current and PWM count for (i=0; i<MAX_DOF; i++)
{
cur_des[i] = tau_des[i] * motor_dir[i];
if (cur_des[i] > 1.0) cur_des[i] = 1.0;
else if (cur_des[i] < -1.0) cur_des[i] = -1.0; }

// send torques
for (int i=0; i<4;i++)
{
// the index order for motors is different from that of encoders vars.pwm_demand[i*4+3] = (short)(cur_des[i*4+0]*800.0); vars.pwm_demand[i*4+2] = (short)(cur_des[i*4+1]*800.0); vars.pwm_demand[i*4+1] = (short)(cur_des[i*4+2]*800.0); vars.pwm_demand[i*4+0] = (short)(cur_des[i*4+3]*800.0);

write_current(CAN_Ch, i, &vars.pwm_demand[4*i]); for(int k=0; k<100000; k++);
}
sendNum++;
curTime += delT;

data_return = 0;
}
}
break;
}
}
}

return 0;
}
37. “MainLoop” 함수에 “rPanelManipulator” 버튼 클릭을 처리하기 위한 코드를 추가한다.

if (!_kbhit())
{
Sleep(5);
if (pSHM)
{
switch (pSHM->cmd.command) {
case CMD_SERVO_ON:
break;
case CMD_SERVO_OFF:
if (pBHand) pBHand->SetMotionType(eMotionType_NONE); break;
case CMD_CMD_1:
if (pBHand) pBHand->SetMotionType(eMotionType_HOME); break;
case CMD_CMD_2:
if (pBHand) pBHand->SetMotionType(eMotionType_READY); break;
case CMD_CMD_3:
if (pBHand) pBHand->SetMotionType(eMotionType_GRASP_3); break;
case CMD_CMD_4:
if (pBHand) pBHand->SetMotionType(eMotionType_GRASP_4); break;
case CMD_CMD_5:
if (pBHand) pBHand->SetMotionType(eMotionType_PINCH_IT); break;
case CMD_CMD_6:
if (pBHand) pBHand->SetMotionType(eMotionType_PINCH_MT); break;
case CMD_CMD_7:
if (pBHand) pBHand->SetMotionType(eMotionType_ENVELOP); break;
case CMD_CMD_8:
if (pBHand) pBHand->SetMotionType(eMotionType_GRAVITY_COMP); break;
case CMD_EXIT:
bRun = false;
break;
}

pSHM->cmd.command = CMD_NULL;
for (i=0; i<MAX_DOF; i++)
{
pSHM->state.slave_state[i].position = q[i]; pSHM->cmd.slave_command[i].torque = tau_des[i]; }
pSHM->state.time = curTime;
}
}

# 38. 마지막으로 “main” 함수에서 변수 초기화 및 “BHand” 객체를 생성하고 삭제하기 위한 코드를

다음과 같이 추가한다.

int _tmain(int argc, _TCHAR* argv[])
{
PrintInstruction();

memset(&vars, 0, sizeof(vars)); memset(q, 0, sizeof(q));
memset(tau_des, 0, sizeof(tau_des)); memset(cur_des, 0, sizeof(cur_des)); curTime = 0.0;

pSHM = getrPanelManipulatorCmdMemory();

if (CreateBHandAlgorithm() && OpenCAN()) MainLoop();

CloseCAN();
DestroyBHandAlgorithm();
closerPanelManipulatorCmdMemory();

return 0;
}
39. 프로젝트 속성에서 “Additional Library Directories”에 “BHand” 라이브러리 폴더를 추가한다.

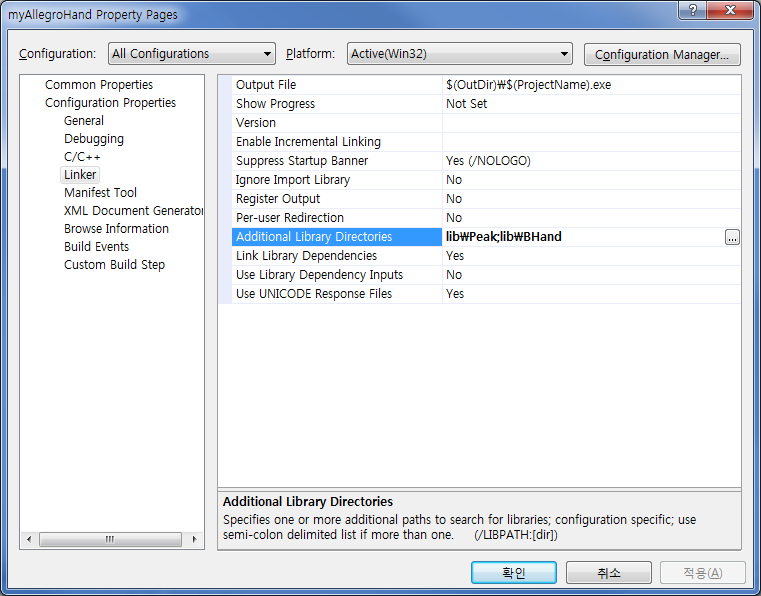
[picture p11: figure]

40. “Additional Dependancies”에 “libBHand.lib”을 추가한다.

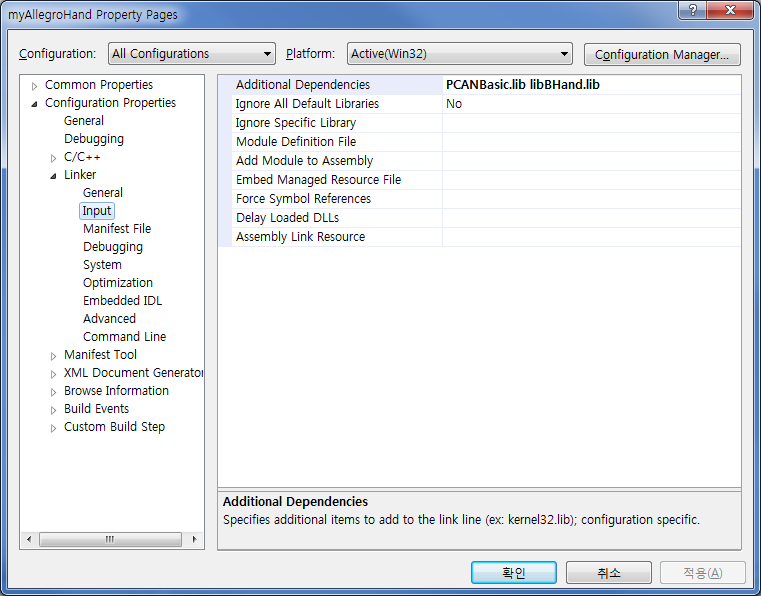
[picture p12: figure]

41. 프로그램 빌드 후 실행한다.

# 42. “rPanelManipulator”의 “Control Panel” 탭에서 “Current Time(sec)”이 실제 시간과 같이 증가함을

우선 확인한다.
43. “rPanelManipulator”에서 “Home”, “Ready”, “Grasp (3)” 등의 버튼을 클릭하여 동작을 확인한다.

# ■ Source code

# myAllegroHand.cpp

// myAllegroHand.cpp : Defines the entry point for the console application. //

#include "stdafx.h"

#include "windows.h"

#include <conio.h>

#include <process.h>

#include <tchar.h>

#include "canAPI.h"

#include "rDeviceAllegroHandCANDef.h" #include "rPanelManipulatorCmdUtil.h" #include "BHand/BHand.h"

///////////////////////////////////////
// for CAN communication
const double delT = 0.003; int CAN_Ch = 0;
bool ioThreadRun = false;
uintptr_t ioThread = 0;
int recvNum = 0;
int sendNum = 0;
double statTime = -1.0;
AllegroHand_DeviceMemory_t vars;

///////////////////////////////////////
// for rPanelManipulator
rPanelManipulatorData_t* pSHM = NULL; double curTime = 0.0;

///////////////////////////////////////
// for BHand library
BHand* pBHand = NULL;
double q[MAX_DOF];
double tau_des[MAX_DOF];
double cur_des[MAX_DOF];
const int enc_offset[MAX_DOF] = { // SAH020CR020 -611, -66016, 1161, 1377,
-342, -66033, -481, 303,
30, -65620, 446, 387,
-3942, -626, -65508, -66768
};
const double enc_dir[MAX_DOF] = { // SAH020CR020 1.0, -1.0, 1.0, 1.0,
1.0, -1.0, 1.0, 1.0,
1.0, -1.0, 1.0, 1.0,
1.0, 1.0, -1.0, -1.0
};
const double motor_dir[MAX_DOF] = { // SAH020CR020 1.0, 1.0, 1.0, 1.0,
1.0, -1.0, -1.0, 1.0,
-1.0, 1.0, 1.0, 1.0,
1.0, 1.0, 1.0, 1.0
};

/////////////////////////////////////// // functions
void PrintInstruction();
void MainLoop();
bool OpenCAN();
void CloseCAN();
int GetCANChannelIndex(const TCHAR* cname); bool CreateBHandAlgorithm();
void DestroyBHandAlgorithm();
void ComputeTorque();

void ComputeTorque()
{
/*memset(tau_des, 0, sizeof(tau_des)); tau_des[0] = 200.0 / 800.0 * motor_dir[0]; return;*/

if (!pBHand) return;

pBHand->SetJointPosition(q); // tell BHand library the current joint positions pBHand->UpdateControl(0);
pBHand->GetJointTorque(tau_des);
}

static unsigned int __stdcall ioThreadProc(void* inst) {
char id_des;
char id_cmd;
char id_src;
int len;
unsigned char data[8];
unsigned char data_return = 0; int i;

while (ioThreadRun)

{
while (0 == get_message(CAN_Ch, &id_cmd, &id_src, &id_des, &len, data, FALSE)) {
switch (id_cmd)
{
case ID_CMD_QUERY_CONTROL_DATA: {
if (id_src >= ID_DEVICE_SUB_01 && id_src <= ID_DEVICE_SUB_04)
{
vars.enc_actual[(id_src-ID_DEVICE_SUB_01)*4 + 0] = (int)(data[0] | (data[1] << 8));
vars.enc_actual[(id_src-ID_DEVICE_SUB_01)*4 + 1] = (int)(data[2] | (data[3] << 8));
vars.enc_actual[(id_src-ID_DEVICE_SUB_01)*4 + 2] = (int)(data[4] | (data[5] << 8));
vars.enc_actual[(id_src-ID_DEVICE_SUB_01)*4 + 3] = (int)(data[6] | (data[7] << 8));
data_return |= (0x01 << (id_src-ID_DEVICE_SUB_01));
recvNum++;
}
if (data_return == (0x01 | 0x02 | 0x04 | 0x08))
{
// convert encoder count to joint angle for (i=0; i<MAX_DOF; i++)
q[i] = (double)(vars.enc_actual[i]*enc_dir[i]-32768-enc_offset[i])*(333.3/65536.0)*(3.141592/180.0);

// compute joint torque
ComputeTorque();

// convert desired torque to desired current and PWM count for (i=0; i<MAX_DOF; i++)
{
cur_des[i] = tau_des[i] * motor_dir[i];
if (cur_des[i] > 1.0) cur_des[i] = 1.0;
else if (cur_des[i] < -1.0) cur_des[i] = -1.0; }

// send torques
for (int i=0; i<4;i++)
{
// the index order for motors is different from that of encoders vars.pwm_demand[i*4+3] = (short)(cur_des[i*4+0]*800.0); vars.pwm_demand[i*4+2] = (short)(cur_des[i*4+1]*800.0); vars.pwm_demand[i*4+1] = (short)(cur_des[i*4+2]*800.0); vars.pwm_demand[i*4+0] = (short)(cur_des[i*4+3]*800.0);

write_current(CAN_Ch, i, &vars.pwm_demand[4*i]); for(int k=0; k<100000; k++);
}
sendNum++;
curTime += delT;

data_return = 0;
}
}
break;
}
}
}

return 0;
}

void MainLoop()
{
bool bRun = true;
int i;

while (bRun)
{
if (!_kbhit())
{
Sleep(5);
if (pSHM)
{
switch (pSHM->cmd.command) {
case CMD_SERVO_ON:
break;
case CMD_SERVO_OFF:
if (pBHand) pBHand->SetMotionType(eMotionType_NONE); break;
case CMD_CMD_1:
if (pBHand) pBHand->SetMotionType(eMotionType_HOME); break;
case CMD_CMD_2:
if (pBHand) pBHand->SetMotionType(eMotionType_READY); break;
case CMD_CMD_3:
if (pBHand) pBHand->SetMotionType(eMotionType_GRASP_3); break;
case CMD_CMD_4:
if (pBHand) pBHand->SetMotionType(eMotionType_GRASP_4); break;
case CMD_CMD_5:
if (pBHand) pBHand->SetMotionType(eMotionType_PINCH_IT); break;
case CMD_CMD_6:
if (pBHand) pBHand->SetMotionType(eMotionType_PINCH_MT); break;
case CMD_CMD_7:
if (pBHand) pBHand->SetMotionType(eMotionType_ENVELOP);

break;
case CMD_CMD_8:
if (pBHand) pBHand->SetMotionType(eMotionType_GRAVITY_COMP); break;
case CMD_EXIT:
bRun = false;
break;
}
pSHM->cmd.command = CMD_NULL; for (i=0; i<MAX_DOF; i++)
{
pSHM->state.slave_state[i].position = q[i]; pSHM->cmd.slave_command[i].torque = tau_des[i]; }
pSHM->state.time = curTime; }
}
else
{
int c = _getch();
switch (c)
{
case 'q':
bRun = false;
break;
}
}
}
}

bool OpenCAN()
{
int ret;

CAN_Ch = GetCANChannelIndex(_T("USBBUS1"));

printf(">CAN(%d): open\n", CAN_Ch);
ret = command_can_open(CAN_Ch);
if(ret < 0)
{
printf("ERROR command_canopen !!! \n"); return false;
}

recvNum = 0;
sendNum = 0;
statTime = 0.0;

ioThreadRun = true;
ioThread = _beginthreadex(NULL, 0, ioThreadProc, NULL, 0, NULL); printf(">CAN: starts listening CAN frames\n");

printf(">CAN: system init\n");
ret = command_can_sys_init(CAN_Ch, 3/*msec*/); if(ret < 0)
{
printf("ERROR command_can_sys_init !!! \n"); command_can_close(CAN_Ch);
return false;
}

printf(">CAN: start periodic communication\n"); ret = command_can_start(CAN_Ch);
if(ret < 0)
{
printf("ERROR command_can_start !!! \n"); command_can_stop(CAN_Ch);
command_can_close(CAN_Ch);
return false;
}

return true;
}

void CloseCAN()
{
int ret;

printf(">CAN: stop periodic communication\n"); ret = command_can_stop(CAN_Ch);
if(ret < 0)
{
printf("ERROR command_can_stop !!! \n"); }

if (ioThreadRun)
{
printf(">CAN: stoped listening CAN frames\n"); ioThreadRun = false;
WaitForSingleObject((HANDLE)ioThread, INFINITE); CloseHandle((HANDLE)ioThread);
ioThread = 0;
}

printf(">CAN(%d): close\n", CAN_Ch);
ret = command_can_close(CAN_Ch);
if(ret < 0) printf("ERROR command_can_close !!! \n"); }

void PrintInstruction()
{
printf("--------------------------------------------------\n"); printf("myAllegroHand\n");
printf("\n");
printf("To quit this program, press 'q'.\n"); printf("--------------------------------------------------\n"); }

int GetCANChannelIndex(const TCHAR* cname)
{
if (!cname) return 0;

if (!_tcsicmp(cname, _T("0")) || !_tcsicmp(cname, _T("PCAN_NONEBUS")) || !_tcsicmp(cname, _T("NONEBUS"))) return 0;
else if (!_tcsicmp(cname, _T("1")) || !_tcsicmp(cname, _T("PCAN_ISABUS1")) || !_tcsicmp(cname, _T("ISABUS1"))) return 1;
else if (!_tcsicmp(cname, _T("2")) || !_tcsicmp(cname, _T("PCAN_ISABUS2")) || !_tcsicmp(cname, _T("ISABUS2"))) return 2;
else if (!_tcsicmp(cname, _T("3")) || !_tcsicmp(cname, _T("PCAN_ISABUS3")) || !_tcsicmp(cname, _T("ISABUS3"))) return 3;
else if (!_tcsicmp(cname, _T("4")) || !_tcsicmp(cname, _T("PCAN_ISABUS4")) || !_tcsicmp(cname, _T("ISABUS4"))) return 4;
else if (!_tcsicmp(cname, _T("5")) || !_tcsicmp(cname, _T("PCAN_ISABUS5")) || !_tcsicmp(cname, _T("ISABUS5"))) return 5;
else if (!_tcsicmp(cname, _T("7")) || !_tcsicmp(cname, _T("PCAN_ISABUS6")) || !_tcsicmp(cname, _T("ISABUS6"))) return 6;
else if (!_tcsicmp(cname, _T("8")) || !_tcsicmp(cname, _T("PCAN_ISABUS7")) || !_tcsicmp(cname, _T("ISABUS7"))) return 7;
else if (!_tcsicmp(cname, _T("8")) || !_tcsicmp(cname, _T("PCAN_ISABUS8")) || !_tcsicmp(cname, _T("ISABUS8"))) return 8;
else if (!_tcsicmp(cname, _T("9")) || !_tcsicmp(cname, _T("PCAN_DNGBUS1")) || !_tcsicmp(cname, _T("DNGBUS1"))) return 9;
else if (!_tcsicmp(cname, _T("10")) || !_tcsicmp(cname, _T("PCAN_PCIBUS1")) || !_tcsicmp(cname, _T("PCIBUS1"))) return 10;
else if (!_tcsicmp(cname, _T("11")) || !_tcsicmp(cname, _T("PCAN_PCIBUS2")) || !_tcsicmp(cname, _T("PCIBUS2"))) return 11;
else if (!_tcsicmp(cname, _T("12")) || !_tcsicmp(cname, _T("PCAN_PCIBUS3")) || !_tcsicmp(cname, _T("PCIBUS3"))) return 12;
else if (!_tcsicmp(cname, _T("13")) || !_tcsicmp(cname, _T("PCAN_PCIBUS4")) || !_tcsicmp(cname, _T("PCIBUS4"))) return 13;
else if (!_tcsicmp(cname, _T("14")) || !_tcsicmp(cname, _T("PCAN_PCIBUS5")) || !_tcsicmp(cname, _T("PCIBUS5"))) return 14;
else if (!_tcsicmp(cname, _T("15")) || !_tcsicmp(cname, _T("PCAN_PCIBUS6")) || !_tcsicmp(cname, _T("PCIBUS6"))) return 15;
else if (!_tcsicmp(cname, _T("16")) || !_tcsicmp(cname, _T("PCAN_PCIBUS7")) || !_tcsicmp(cname, _T("PCIBUS7"))) return 16;
else if (!_tcsicmp(cname, _T("17")) || !_tcsicmp(cname, _T("PCAN_PCIBUS8")) || !_tcsicmp(cname, _T("PCIBUS8"))) return 17;
else if (!_tcsicmp(cname, _T("18")) || !_tcsicmp(cname, _T("PCAN_USBBUS1")) || !_tcsicmp(cname, _T("USBBUS1"))) return 18;
else if (!_tcsicmp(cname, _T("19")) || !_tcsicmp(cname, _T("PCAN_USBBUS2")) || !_tcsicmp(cname, _T("USBBUS2"))) return 19;
else if (!_tcsicmp(cname, _T("20")) || !_tcsicmp(cname, _T("PCAN_USBBUS3")) || !_tcsicmp(cname, _T("USBBUS3"))) return 20;
else if (!_tcsicmp(cname, _T("21")) || !_tcsicmp(cname, _T("PCAN_USBBUS4")) || !_tcsicmp(cname, _T("USBBUS4"))) return 21;
else if (!_tcsicmp(cname, _T("22")) || !_tcsicmp(cname, _T("PCAN_USBBUS5")) || !_tcsicmp(cname, _T("USBBUS5"))) return 22;
else if (!_tcsicmp(cname, _T("23")) || !_tcsicmp(cname, _T("PCAN_USBBUS6")) || !_tcsicmp(cname, _T("USBBUS6"))) return 23;
else if (!_tcsicmp(cname, _T("24")) || !_tcsicmp(cname, _T("PCAN_USBBUS7")) || !_tcsicmp(cname, _T("USBBUS7"))) return 24;
else if (!_tcsicmp(cname, _T("25")) || !_tcsicmp(cname, _T("PCAN_USBBUS8")) || !_tcsicmp(cname, _T("USBBUS8"))) return 25;
else if (!_tcsicmp(cname, _T("26")) || !_tcsicmp(cname, _T("PCAN_PCCBUS1")) || !_tcsicmp(cname, _T("PCCBUS1"))) return 26;
else if (!_tcsicmp(cname, _T("27")) || !_tcsicmp(cname, _T("PCAN_PCCBUS2")) || !_tcsicmp(cname, _T("PCCBUS2"))) return 271;
else
return 0;
}

bool CreateBHandAlgorithm()
{
pBHand = bhCreateRightHand(); if (!pBHand) return false; pBHand->SetTimeInterval(delT); return true;
}

void DestroyBHandAlgorithm() {
if (pBHand)
{
delete pBHand;
pBHand = NULL;
}
}

int _tmain(int argc, _TCHAR* argv[]) {
PrintInstruction();

memset(&vars, 0, sizeof(vars)); memset(q, 0, sizeof(q));
memset(tau_des, 0, sizeof(tau_des)); memset(cur_des, 0, sizeof(cur_des)); curTime = 0.0;

pSHM = getrPanelManipulatorCmdMemory();

if (CreateBHandAlgorithm() && OpenCAN()) MainLoop();

CloseCAN();
DestroyBHandAlgorithm();
closerPanelManipulatorCmdMemory();

return 0;
}

# canAPI.h

/*
*\brief API for communication over CAN bus
*\detailed The API for communicating with the various motor controllers
* | over the CAN bus interface on the robot hand
*
*$Author: Sangyup Yi $
*$Date: 2012/5/11 23:34:00 $
*$Revision: 1.0 $
*/

#ifndef _CANDAPI_H

#define _CANDAPI_H

#include "canDef.h"

CANAPI_BEGIN

#ifndef FALSE

#define FALSE (0)

#endif

#ifndef TRUE

#define TRUE (1)

#endif

/*=====================*/
/* | Defines | */
/*=====================*/
//constants
#define TX_QUEUE_SIZE | (32)

#define RX_QUEUE_SIZE | (32)

#define TX_TIMEOUT | (5)

#define RX_TIMEOUT | (5)

#define mbxID | (0)

#define BASE_ID | (0)

#define MAX_BUS | (256)

/******************/
/* CAN device API */
/******************/
int command_can_open(int ch); int command_can_reset(int ch);
int command_can_close(int ch);

int command_can_sys_init(int ch, int period_msec); int command_can_start(int ch);
int command_can_stop(int ch);

int write_current(int ch, int findex, short* pwm);

int get_message(int ch, char* cmd, char* src, char* des, int* len, unsigned char* data, int blocking);

CANAPI_END

#endif

# canDef.h

/*
*\brief Constants and enums for CAN communication *
*$Author: Sangyup Yi $
*$Date: 2012/5/11 23:34:00 $
*$Revision: 1.0 $
*/

#ifndef _CANDEF_H

#define _CANDEF_H

#ifdef USING_NAMESPACE_CANAPI

# | define CANAPI_BEGIN namespace CANAPI {

# | define CANAPI_END };

#else

# define CANAPI_BEGIN

# define CANAPI_END

#endif

CANAPI_BEGIN

typedef struct{
unsigned char STD_EXT;
unsigned long msg_id; | // message identifier
unsigned char data_length; | //
char | data[8]; | // data array
} can_msg;
#define | STD | (bool)0

#define | EXT | (bool)1

///////////////////////////////////////////////
// Define Control Board ID number
#define ID_COMMON | 0x01

#define ID_DEVICE_MAIN | 0x02

#define ID_DEVICE_SUB_01 0x03

#define ID_DEVICE_SUB_02 0x04

#define ID_DEVICE_SUB_03 0x05

#define ID_DEVICE_SUB_04 0x06 #define ID_DEVICE_SUB_05 0x07 #define ID_DEVICE_SUB_06 0x08 #define ID_DEVICE_SUB_07 0x09 #define ID_DEVICE_SUB_08 0x0a #define ID_DEVICE_SUB_09 0x0b #define ID_DEVICE_SUB_10 0x0c

////////////////////////////////////////////////
// Define CAN Command
#define ID_CMD_SET_SYSTEM_ON | 0x01

#define ID_CMD_SET_SYSTEM_OFF | 0x02

#define ID_CMD_SET_PERIOD | 0x03

#define ID_CMD_SET_MODE_JOINT | 0x04

#define ID_CMD_SET_MODE_TASK | 0x05

#define ID_CMD_SET_TORQUE_1 | 0x06

#define ID_CMD_SET_TORQUE_2 | 0x07

#define ID_CMD_SET_TORQUE_3 | 0x08

#define ID_CMD_SET_TORQUE_4 | 0x09

#define ID_CMD_SET_POSITION_1 | 0x0a

#define ID_CMD_SET_POSITION_2 | 0x0b

#define ID_CMD_SET_POSITION_3 | 0x0c

#define ID_CMD_SET_POSITION_4 | 0x0d

#define ID_CMD_QUERY_STATE_DATA | 0x0e

#define ID_CMD_QUERY_CONTROL_DATA | 0x0f

////////////////////////////////////////////////
// Define Control Channel in Device
#define MOTOR_CH_1 | 0x01

#define MOTOR_CH_2 | 0x02

#define MOTOR_CH_3 | 0x03

#define MOTOR_CH_4 | 0x04

#define MOTOR_CH_ALL | 0x05

#define DEVICE_SYSTEM | 0x06

////////////////////////////////////////////////
// Define State
#define STATE_CH1 | 0x01

#define STATE_CH2 | 0x02

#define STATE_CH3 | 0x04

#define STATE_CH4 | 0x08

#define STATE_ALL | 0x10

#define STATE_SYSTEM | 0x80

////////////////////////////////////////////////
// | Define Motor State
#define SYSTEM_ON | 0x01

#define SYSTEM_OFF | 0x02

#define MOTOR_RUN | 0x04

#define MOTOR_STOP | 0x08

#define MOTOR_DIR_CW | 0x01

#define MOTOR_DIR_CCW 0x02

#define ON 1

#define OFF 0

////////////////////////////////////////////////

CANAPI_END

#endif

# rDeviceAllegroHandCANDef.h

#ifndef __RDEVICEALLEGROHANDCANDEF_H__ #define __RDEVICEALLEGROHANDCANDEF_H__

#define MAX_DOF 16

typedef struct tagDeviceMemory_AllegroHand {
int enc_actual[MAX_DOF];
short pwm_actual[MAX_DOF]; short pwm_demand[MAX_DOF];
} AllegroHand_DeviceMemory_t;

#endif // __RDEVICEALLEGROHANDCANDEF_H__

# canAPI.cpp

/*======================*/
/* | Includes | */
/*======================*/ //system headers
#include <stdio.h>

#include <errno.h>

#ifndef _WIN32

#include <inttypes.h>

#include <pthread.h>

#include <syslog.h>

#include <unistd.h>

#else

#include <windows.h>

#endif

#include <malloc.h>

#include <assert.h>

//project headers
extern "C" {
#include "Peak/PCANBasic.h" }

#include "canDef.h"

#include "canAPI.h"

CANAPI_BEGIN

/*=====================*/
/* | Defines | */
/*=====================*/
//macros
#define isAlpha(c) ( ((c >= 'A') && (c <= 'Z')) ? 1 : 0 ) #define isSpace(c) ( (c == ' ') ? 1 : 0 )

#define isDigit(c) ( ((c >= '0') && (c <= '9')) ? 1 : 0 )

#define ADDR2NODE(x) ((((x) >> 5) & 0x001F) - BASE_ID)

#define NODE2ADDR(x) (((mbxID + BASE_ID) << 5) | ((x) + BASE_ID))

#define GROUPID(n) | (((mbxID + BASE_ID) << 5) | (0x0400 + (n)))

#define BROADCAST | (GROUPID(0))

#define Border(Value,Min,Max) (Value<Min)?Min:((Value>Max)?Max:Value) //typedefs & structs

typedef unsigned long DWORD;

/*=========================================*/
/* | Global file-scope variables | */
/*=========================================*/

TPCANHandle canDev[MAX_BUS] = {
PCAN_NONEBUS, // Undefined/default value for a PCAN bus

PCAN_ISABUS1, // PCAN-ISA interface, channel 1 PCAN_ISABUS2, // PCAN-ISA interface, channel 2 PCAN_ISABUS3, // PCAN-ISA interface, channel 3 PCAN_ISABUS4, // PCAN-ISA interface, channel 4 PCAN_ISABUS5, // PCAN-ISA interface, channel 5 PCAN_ISABUS6, // PCAN-ISA interface, channel 6 PCAN_ISABUS7, // PCAN-ISA interface, channel 7 PCAN_ISABUS8, // PCAN-ISA interface, channel 8

PCAN_DNGBUS1, // PCAN-Dongle/LPT interface, channel 1

PCAN_PCIBUS1, // PCAN-PCI interface, channel 1 PCAN_PCIBUS2, // PCAN-PCI interface, channel 2 PCAN_PCIBUS3, // PCAN-PCI interface, channel 3 PCAN_PCIBUS4, // PCAN-PCI interface, channel 4 PCAN_PCIBUS5, // PCAN-PCI interface, channel 5 PCAN_PCIBUS6, // PCAN-PCI interface, channel 6 PCAN_PCIBUS7, // PCAN-PCI interface, channel 7 PCAN_PCIBUS8, // PCAN-PCI interface, channel 8

PCAN_USBBUS1, // PCAN-USB interface, channel 1 PCAN_USBBUS2, // PCAN-USB interface, channel 2 PCAN_USBBUS3, // PCAN-USB interface, channel 3 PCAN_USBBUS4, // PCAN-USB interface, channel 4 PCAN_USBBUS5, // PCAN-USB interface, channel 5 PCAN_USBBUS6, // PCAN-USB interface, channel 6 PCAN_USBBUS7, // PCAN-USB interface, channel 7 PCAN_USBBUS8, // PCAN-USB interface, channel 8

PCAN_PCCBUS1, // PCAN-PC Card interface, channel 1 PCAN_PCCBUS2, // PCAN-PC Card interface, channel 2 };

/*==========================================*/
/* | Private functions prototypes | */
/*==========================================*/
int canReadMsg(int bus, int *id, int *len, unsigned char *data, int blocking); int canSendMsg(int bus, int id, char len, unsigned char *data, int blocking);

/*========================================*/
/* | Public functions (CAN API) | */
/*========================================*/ int initCAN(int bus){
TPCANStatus Status = PCAN_ERROR_OK;
| char strMsg[256];
TPCANBaudrate Baudrate = PCAN_BAUD_1M;
| TPCANType HwType = 0; DWORD IOPort = 0; WORD Interrupt = 0;

Status = CAN_Initialize(canDev[bus], Baudrate, HwType, IOPort, Interrupt); if (Status != PCAN_ERROR_OK)
| {
CAN_GetErrorText(Status, 0, strMsg);
printf("initCAN(): CAN_Initialize() failed with error %ld\n", Status); printf("%s\n", strMsg);
| return Status; }

Status = CAN_FilterMessages(
| canDev[bus],
((unsigned long)(ID_CMD_QUERY_CONTROL_DATA) <<6) | ((unsigned long)ID_DEVICE_MAIN <<3) | ((unsigned long)ID_DEVICE_SUB_01),
((unsigned long)(ID_CMD_QUERY_CONTROL_DATA) <<6) | ((unsigned long)ID_DEVICE_MAIN <<3) | ((unsigned long)ID_DEVICE_SUB_04),
PCAN_MESSAGE_STANDARD);
if (Status != PCAN_ERROR_OK)
| {
CAN_GetErrorText(Status, 0, strMsg);
printf("initCAN(): CAN_FilterMessages() failed with error %ld\n", Status); printf("%s\n", strMsg);
//return Status;
| }

Status = CAN_Reset(canDev[bus]); if (Status != PCAN_ERROR_OK)
| {
CAN_GetErrorText(Status, 0, strMsg);
printf("initCAN(): CAN_Reset() failed with error %ld\n", Status); printf("%s\n", strMsg);
//return Status;
| }

return 0; // PCAN_ERROR_OK }

int freeCAN(int bus){
TPCANStatus Status = PCAN_ERROR_OK;
| char strMsg[256];

Status = CAN_Uninitialize(canDev[bus]); if (Status != PCAN_ERROR_OK)
| {
CAN_GetErrorText(Status, 0, strMsg);
printf("freeCAN(): CAN_Uninitialize() failed with error %ld\n", Status); printf("%s\n", strMsg);
| return Status; }

return 0; // PCAN_ERROR_OK
}

int canReadMsg(int bus, int *id, int *len, unsigned char *data, int blocking){
| TPCANMsg CANMsg;
TPCANTimestamp CANTimeStamp;
TPCANStatus Status = PCAN_ERROR_OK;
| char strMsg[256]; int i;

// We execute the "Read" function of the PCANBasic
| //
Status = CAN_Read(canDev[bus], &CANMsg, &CANTimeStamp);

if (Status != PCAN_ERROR_OK)
| {
if (Status != PCAN_ERROR_QRCVEMPTY)
| {
| | CAN_GetErrorText(Status, 0, strMsg); printf("canReadMsg(): CAN_Read() failed with error %ld\n", Status); printf("%s\n", strMsg);
| } return Status; }
| *id = CANMsg.ID; *len = CANMsg.LEN;

for(i = 0; i < CANMsg.LEN; i++) data[i] = CANMsg.DATA[i];

| return 0;
}

int canSendMsg(int bus, int id, char len, unsigned char *data, int blocking){
| TPCANMsg CANMsg;

TPCANStatus Status = PCAN_ERROR_OK; char strMsg[256];
int i;

CANMsg.ID = id;
CANMsg.LEN = len & 0x0F;
for(i = 0; i < len; i++)
CANMsg.DATA[i] = data[i];
CANMsg.MSGTYPE = PCAN_MESSAGE_STANDARD;

Status = CAN_Write(canDev[bus], &CANMsg);
if (Status != PCAN_ERROR_OK)
{
CAN_GetErrorText(Status, 0, strMsg);
printf("canSendMsg(): CAN_Write() failed with error %ld\n", Status); printf("%s\n", strMsg);
return Status;
}

return 0;
}

/*========================================*/
/* | CAN API | */
/*========================================*/ int command_can_open(int ch)
{
assert(ch >= 0 && ch < MAX_BUS);
| DWORD ret;

printf("<< CAN: Open Channel...\n");
| ret = initCAN(ch); if (ret != 0) return ret; printf("\t- Ch.%2d (OK)\n", ch); printf("\t- Done\n");
| return 0;
}

int command_can_reset(int ch) {
| return -1;
}

int command_can_close(int ch)
{
assert(ch >= 0 && ch < MAX_BUS);

TPCANStatus Status = PCAN_ERROR_OK;
| char strMsg[256]; printf("<< CAN: Close...\n");

Status = CAN_Uninitialize(canDev[ch]); if (Status != PCAN_ERROR_OK)
| {
| | CAN_GetErrorText(Status, 0, strMsg); printf("freeCAN(): CAN_Uninitialize() failed with error %ld\n", Status); printf("%s\n", strMsg);

return Status;
| }
| printf("\t- Done\n"); return 0; // PCAN_ERROR_OK

}

int command_can_sys_init(int ch, int period_msec) {
assert(ch >= 0 && ch < MAX_BUS);
| long Txid; unsigned char data[8]; int ret;
Txid = ((unsigned long)ID_CMD_SET_PERIOD<<6) | ((unsigned long)ID_COMMON <<3) | ((unsigned long)ID_DEVICE_MAIN);
data[0] = (unsigned char)period_msec;
ret = canSendMsg(ch, Txid, 1, data, TRUE);
| Sleep(10);
Txid = ((unsigned long)ID_CMD_SET_MODE_TASK<<6) | ((unsigned long)ID_COMMON <<3) | ((unsigned long)ID_DEVICE_MAIN);
ret = canSendMsg(ch, Txid, 0, data, TRUE);
| Sleep(10);
Txid = ((unsigned long)ID_CMD_QUERY_STATE_DATA<<6) | ((unsigned long)ID_COMMON <<3) | ((unsigned long)ID_DEVICE_MAIN);
ret = canSendMsg(ch, Txid, 0, data, TRUE);
| return 0;
}

int command_can_start(int ch)
{
assert(ch >= 0 && ch < MAX_BUS);
| long Txid; unsigned char data[8]; int ret;

Txid = ((unsigned long)ID_CMD_QUERY_STATE_DATA<<6) | ((unsigned long)ID_COMMON <<3) | ((unsigned long)ID_DEVICE_MAIN);
ret = canSendMsg(ch, Txid, 0, data, TRUE);

Sleep(10);

Txid = ((unsigned long)ID_CMD_SET_SYSTEM_ON<<6) | ((unsigned long)ID_COMMON <<3) | ((unsigned long)ID_DEVICE_MAIN);
ret = canSendMsg(ch, Txid, 0, data, TRUE);

return 0;
}

int command_can_stop(int ch)
{
assert(ch >= 0 && ch < MAX_BUS);

long Txid;
unsigned char data[8];
int ret;
Txid = ((unsigned long)ID_CMD_SET_SYSTEM_OFF<<6) | ((unsigned long)ID_COMMON <<3) | ((unsigned long)ID_DEVICE_MAIN);
ret = canSendMsg(ch, Txid, 0, data, TRUE);

return 0;
}

int write_current(int ch, int findex, short* pwm)
{
assert(ch >= 0 && ch < MAX_BUS);

long Txid;
unsigned char data[8];
int ret;

if (findex >= 0 && findex < 4) {
data[0] = (unsigned char)( (pwm[0] >> 8) & 0x00ff); data[1] = (unsigned char)(pwm[0] & 0x00ff);

data[2] = (unsigned char)( (pwm[1] >> 8) & 0x00ff); data[3] = (unsigned char)(pwm[1] & 0x00ff);

data[4] = (unsigned char)( (pwm[2] >> 8) & 0x00ff); data[5] = (unsigned char)(pwm[2] & 0x00ff);

data[6] = (unsigned char)( (pwm[3] >> 8) & 0x00ff);
data[7] = (unsigned char)(pwm[3] & 0x00ff);
Txid = ((unsigned long)(ID_CMD_SET_TORQUE_1 + findex)<<6) | ((unsigned long)ID_COMMON <<3) | ((unsigned long)ID_DEVICE_MAIN);
ret = canSendMsg(ch, Txid, 8, data, TRUE);
}
else
return -1;

return 0;
}

int get_message(int ch, char* cmd, char* src, char* des, int* len, unsigned char* data, int blocking) {
int err;
unsigned long Rxid;

err = canReadMsg(ch, (int*)&Rxid, len, data, blocking); if (!err)
{
*cmd = (char)( (Rxid >> 6) & 0x1f ); *des = (char)( (Rxid >> 3) & 0x07 ); *src = (char)( Rxid & 0x07);
}
else
{
return err;
}
return 0;
}

CANAPI_END

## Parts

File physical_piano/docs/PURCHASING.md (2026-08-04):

# Physical Piano — Parts to Purchase

Shopping list for the 11-key physical piano. **18 switches**: one per white key
(11) and one per black key (7) — the black keys are now clickable too.

Prices are approximate and are there for budgeting — confirm
at checkout. Links point to reputable distributors; equivalents are fine.

---

## Order status — placed 2026-08-04

Ordered by the supervisor (from `Physical_Piano_BOM.docx`, highlighted rows):

**Switches** Adafruit #4952 × 2 packs (20 pcs) · **Arduino** Uno R3, official ·
**Sound** enclosed piezo #1739 · **Wiring** breadboard #239, USB A–B #62,
hookup wire #3111, perfboard #1606 · **Mechanical** K&S 3 mm brass rod 3-pack
*and* the longer McMaster 3 mm stainless (2 ft), M3 assortment kit, CA glue.

**Not ordered — check before you need them:**

| Item | Why it might matter |
|---|---|
| Soldering iron kit | Not highlighted — presumably already in lab stock. Confirm before the perfboard stage. |
| M3 standoffs, 12 mm | **Laser route only.** Needed if that route is chosen; the printed route's feet are integral. |

**Two notes on what *was* ordered:**

- The **M3 kit is a laser-route part in practice.** `piano_base_printed.scad`
  has no bolt holes anywhere — its tiles register on 3 mm dowels and are glued.
  The laser route uses M3 in 27 places. If the printed route is chosen the kit
  goes spare, unless seam bolt holes are added to the CAD first.
- **Both rod lengths are useful, and you need both if the route is still open.**
  The printed route wants three tile-length pieces (250 / 200 / 100 mm), which
  the 300 mm K&S rods cover. The laser route wants ONE continuous pin —
  581 mm — which only the 2 ft McMaster rod covers.

---

## 1. Key switches

### ✅ CHOSEN: mechanical keyboard switches (MX-style linear)

*Decided. The CAD has been converted to a 14 × 14 mm MX plate mount, and the
separate return springs have been removed from the design.*

An MX-style linear switch bundles **switch + return spring + 4 mm travel +
keycap mount** into one part. That removes the separate return spring, the
spring seats, and most of the travel-tuning from the build. Actuation ~45–60 gf
is far below our weakest finger (362 gf), so every finger triggers it reliably.

| Qty | Item | ~Price | Link |
|----:|---|---:|---|
| 2 packs (20 pcs, 2 spare) | Kailh linear red switches, 10-pack (MX-compatible) | ~$6/pack | [Adafruit #4952](https://www.adafruit.com/product/4952) |
| — | *or* Cherry MX Red 45 g linear, 10-pack | ~$12/pack | [Amazon MX1A-L1NN](https://www.amazon.com/Original-Cherry-Switches-Mechanical-Keyboard/dp/B09J3GSY6Y) · [MechanicalKeyboards.com](https://mechanicalkeyboards.com/products/cherry-mx-red-45g-linear) |

### ~~Option B: snap-action micro switches~~ (not chosen — kept for reference)

Would need a separate return spring per key.

| Qty | Item | ~Price | Link |
|----:|---|---:|---|
| 14 (11 + 3 spare) | Omron **D2F-01F** ultra-subminiature, low operating force (~0.98 N), 0.1 A — plenty for logic-level switching | ~$2 ea | [DigiKey D2F-01F](https://www.digikey.com/en/products/detail/omron-electronics-inc-emc-div/D2F-01F/83266) |
| — | *alt* Omron D2F-01 (standard force) | ~$1.50 ea | [DigiKey D2F-01](https://www.digikey.com/en/products/detail/omron-electronics-inc-emc-div/D2F-01/83260) |
| 1 assortment | Small compression springs (~8 mm OD, light force) for key return | ~$20 | [McMaster compression spring assortments](https://www.mcmaster.com/products/compression-spring-assortments/) |

Datasheet (confirm operating force before ordering):
[Omron D2F series PDF](https://omronfs.omron.com/en_US/ecb/products/pdf/en-d2f.pdf)

---

## 2. Microcontroller & sound

| Qty | Item | ~Price | Link |
|----:|---|---:|---|
| 1 | Arduino Uno R3 (official) | ~$28 | [Arduino Store](https://store-usa.arduino.cc/products/arduino-uno-rev3) · [SparkFun](https://www.sparkfun.com/arduino-uno-r3.html) |
| — | *or* budget-compatible Uno R3 clone (works identically) | ~$13 | [ELEGOO UNO R3](https://us.elegoo.com/products/elegoo-uno-r3-board) |
**No speaker is required.** The computer plays the notes — the Arduino is a
pure key scanner. All 18 usable Uno pins go to switches, so there is no pin
left for a speaker and none is needed. The enclosed piezo already ordered is
still useful for bench-testing switches before the PC listener is running, but
it is not part of the finished instrument.

| 1 *(optional)* | Enclosed piezo element — bench testing only | ~$3 | [Adafruit #1739](https://www.adafruit.com/product/1739) |

---

## 3. Wiring & assembly

Wire the 11 switches in two stages: a **breadboard** to bring up and test the
firmware before any key exists (no soldering, fully reversible), then a
**soldered perfboard** for the permanent build. Solder is worth the extra step
here — the keys get struck repeatedly at 362–520 gf, and a breadboard's
friction-fit connections can work loose under that kind of repeated shock,
which is not a failure mode you want mid-session. *If you'd rather not solder*,
the no-solder screw-terminal option below is a durable middle ground.

| Qty | Item | ~Price | Link |
|----:|---|---:|---|
| 1 | Full-size solderless breadboard | ~$5 | [Adafruit #239](https://www.adafruit.com/product/239) — bring-up/testing only |
| 1 | USB A–B cable (Uno) | ~$6 | [Adafruit #62](https://www.adafruit.com/product/62) · [Arduino Store](https://store-usa.arduino.cc/products/usb-2-0-cable-type-a-b) — likely already in lab stock |
| 1 | Hookup wire, 22 AWG stranded, 6 colors — 18 signals + ground | ~$15 | [Adafruit #3111](https://www.adafruit.com/product/3111) · [SparkFun](https://www.sparkfun.com/hook-up-wire-assortment-stranded-22-awg.html) |
| 1 | Perfboard / prototyping board | ~$11 | [Adafruit #1606](https://www.adafruit.com/product/1606) — final build |
| 1 | Beginner soldering iron kit (iron, stand, solder, sucker, wick) | ~$20 | [Amazon — LCDalternatives kit](https://www.amazon.com/Beginner-Soldering-LCDalternatives-v3-solder/dp/B00SH2MOB6) |
| 1 pack | K&S 3 mm brass rod, 3-pack (300 mm each) — hinge pin | ~$8 | [Amazon](https://www.amazon.com/Round-Brass-Rod-Diameter-Engineering/dp/B013Y2EACO) — 300 mm covers the printed route's per-tile pins. The laser route needs one continuous 581 mm pin: use the [2 ft McMaster 3 mm stainless](https://www.mcmaster.com/products/rods/diameter~3-mm/stainless-steel-4~/system-of-measurement~metric/length~24/length~2-ft/) rather than butting two rods at a bracket |
| 1 | M3 nut/bolt/washer assortment kit — **laser route**; the printed base has no bolt holes | ~$12 | [Amazon](https://www.amazon.com/Assortment-Stainless-Washers-Assorted-Machine/dp/B0BC24J6SS) |
| 6 | M3 standoffs, 12 mm — **laser route only**; the printed route has feet built into the base cells | ~$9 | [Amazon](https://www.amazon.com/Hilitchi-Female-Standoff-Assortment-Motherboard/dp/B01LZ6PXCY) |
| 1 | Gorilla super glue (cyanoacrylate) | ~$7 | [Amazon](https://www.amazon.com/Gorilla-Super-Glue-Gram-Clear/dp/B00KPYB05A) — **printed route: tile seams only. Do NOT glue the black keys** — they are keycaps that push onto a switch stem and must come off again |

**No-solder alternative** — skip the perfboard + soldering kit above and use
this instead:

| Qty | Item | ~Price | Link |
|----:|---|---:|---|
| 1 | Screw-terminal shield for Arduino Uno | ~$15 | [Amazon](https://www.amazon.com/Screw-Terminal-Shield-Arduino-Uno/dp/B0F5NVVY1Q) |

Each wire clamps under a screw instead of being soldered — less permanent than
solder, but far more robust than a bare breadboard, with no tools to learn.

---

## 4. 3D printing (via CMU TechSpark — not a purchase, a billed service)

See [TECHSPARK_PLAN.md](TECHSPARK_PLAN.md) for the full process.

**Rough material estimate** (PLA, from part volumes — the slicer at TechSpark
gives the real number):

| Part | Qty | ~Mass each | ~Total |
|---|----:|---:|---:|
| White key lever | 11 | ~16 g | ~175 g |
| Base cell | 11 | ~23 g | ~255 g |
| Black key | 7 | ~9 g | ~65 g |
| Integral feet | 6 pairs | ~0.9 g | ~6 g |
| | | **Total** | **~502 g** |

At PLA **$0.64/g** → **~$321**.

On the laser route the printed base cells are replaced by **12 small hinge
brackets** (~3 g each), so printing drops to ~275 g → **~$176**, plus the laser
sheets and machine time.

> 💡 **Laser-cut base — worth discussing, mainly for accuracy.** TechSpark also
> offers **laser cutting**. Re-authoring the base as flat layers (see
> [`../cad/piano_base_laser.scad`](../cad/piano_base_laser.scad)) cuts all 11 switch
> holes in **one operation on one sheet**, so the 50 mm pitch the arm is
> calibrated to has no tile seams to drift across. The printed base has to be
> split into 3 tiles for a 254 mm bed.
>
> On cost, be realistic: printed mass drops from ~502 g to ~275 g (**$321 →
> ~$176**), but laser time is billed hourly and is not quoted on the services
> page, so the net saving is more like **$40–90, not half**. Treat the pitch
> accuracy as the reason and the cost as a bonus.

---

## Budget summary

| Category | Estimate |
|---|---:|
| Switches | ~$12 |
| Arduino + optional test piezo | ~$31 |
| Wiring & assembly — solder path (breadboard + perfboard + soldering kit) | ~$93 |
| *or* wiring & assembly — no-solder path (breadboard + screw-terminal shield) | *~$77* |
| **Parts subtotal — solder path** | **~$136** |
| *Parts subtotal — no-solder path* | *~$120* |
| Fabrication — all 3D printed | ~$321 |
| Fabrication — laser-cut base + printed keys | ~$176 print + laser time |
| **Grand total — solder path + all-printed** | **~$457** |
| *Grand total — no-solder path + laser-cut* | *~$296 + laser time* |

The soldering kit (~$20) is a one-time purchase — skip it on the no-solder path,
or keep it if the lab wants one on hand for future builds.

**Suggested first purchase:** buy the electronics now (~$100) so the firmware and
listener can be bench-tested on a breadboard while the mechanical parts are still
being printed. The two tracks are independent.

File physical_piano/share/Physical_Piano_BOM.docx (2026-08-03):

BCI ARM AND HAND PIANO TASK

Physical Piano — Parts to Purchase

Shopping list for the 11-key physical piano that replaces the toy playmat. Every dimension in the design has been measured against the robot on the bench.

Parts to purchase ~$135 Sections 1–3, solder path | Fabrication $176–315 Billed by TechSpark | Keys 11 + 7 White, plus decorative black

Suggested first step: order Sections 1–3 now. Electronics and mechanical fabrication are independent — with these parts on hand, the switches, sound, and tuning software can be built and tested on a breadboard while the keys are still being made at TechSpark.

## 01 Key Switches

MX-style linear switches. Each supplies the electrical contact, the return spring, and 4 mm of travel in one part. They actuate at ~45 gf — far below the robot’s weakest finger, measured at 362 gf.

Item | Qty | Price | Source
Kailh linear red switches, 10-pack MX-compatible. Two packs covers 11 keys plus 9 spares. | 2 packs | $12 | Adafruit #4952 (https://www.adafruit.com/product/4952)
Cherry MX Red 45g, 10-pack Equivalent alternative if Kailh is out of stock. | — | $24 | MechanicalKeyboards (https://mechanicalkeyboards.com/products/cherry-mx-red-45g-linear) · Amazon (https://www.amazon.com/Original-Cherry-Switches-Mechanical-Keyboard/dp/B09J3GSY6Y)

## 02 Microcontroller and Sound

The Arduino reads the 11 keys and plays one tone per key. Pitches are set from a computer over USB and saved on the board.

Item | Qty | Price | Source
Arduino Uno R3 Official board. | 1 | $28 | Arduino Store (https://store-usa.arduino.cc/products/arduino-uno-rev3) · SparkFun (https://www.sparkfun.com/arduino-uno-r3.html)
Uno R3 compatible board Budget option, functionally identical. | — | $13 | ELEGOO (https://us.elegoo.com/products/elegoo-uno-r3-board)
Piezo buzzer Driven directly by the Arduino; no amp needed. | 1 | $2 | Adafruit #160 (https://www.adafruit.com/product/160)
Enclosed piezo element Optional, louder than the bare buzzer. | 1 | $3 | Adafruit #1739 (https://www.adafruit.com/product/1739)

## 03 Wiring and Assembly

Bring up the firmware on a breadboard first (no soldering, fully reversible), then solder a permanent perfboard build — the keys are struck repeatedly at 362–520 gf, which can work a breadboard's connections loose over time.

Item | Qty | Price | Source
Full-size solderless breadboard Bring-up and testing only. | 1 | $5 | Adafruit #239 (https://www.adafruit.com/product/239)
USB A–B cable Powers the Arduino; carries the tuning connection. Likely already in lab stock. | 1 | $6 | Adafruit #62 (https://www.adafruit.com/product/62) · Arduino Store (https://store-usa.arduino.cc/products/usb-2-0-cable-type-a-b)
Hookup wire, 22 AWG stranded 11 signal lines plus a common ground, six colors. | 1 set | $15 | Adafruit #3111 (https://www.adafruit.com/product/3111) · SparkFun (https://www.sparkfun.com/hook-up-wire-assortment-stranded-22-awg.html)
Perfboard Ground bus for the 11 switch commons — final build. | 1 | $11 | Adafruit #1606 (https://www.adafruit.com/product/1606)
Beginner soldering iron kit Iron, stand, solder, sucker, wick. | 1 | $20 | Amazon (https://www.amazon.com/Beginner-Soldering-LCDalternatives-v3-solder/dp/B00SH2MOB6)
K&S 3 mm brass rod, 3-pack Hinge pins for the key levers — brass works as well as steel here and is easier to cut. | 1 | $8 | Amazon (https://www.amazon.com/Round-Brass-Rod-Diameter-Engineering/dp/B013Y2EACO)
M3 nut/bolt/washer assortment kit Screws and nuts for joining base sections. | 1 set | $12 | Amazon (https://www.amazon.com/Assortment-Stainless-Washers-Assorted-Machine/dp/B0BC24J6SS)
Gorilla super glue (cyanoacrylate) Sets the black keys into their locating grooves. | 1 | $7 | Amazon (https://www.amazon.com/Gorilla-Super-Glue-Gram-Clear/dp/B00KPYB05A)

No-solder alternative: skip the perfboard and soldering kit above and use a screw-terminal shield instead — each wire clamps under a screw. Less permanent than solder but far more robust than a bare breadboard. Amazon, ~$15 (https://www.amazon.com/Screw-Terminal-Shield-Arduino-Uno/dp/B0F5NVVY1Q)

## 04 Fabrication — Not a Purchase

Keys, base, and black keys are made at CMU TechSpark and billed to a university account. PLA is $0.64/gram.

Item | Qty | Price | Source
All parts 3D printed ~490 g. Base prints as three tiles — the printers are only 10″ wide — so the 50 mm key pitch must survive two joins. | — | $315
Laser-cut base + printed keys ~275 g printed, plus laser time. Cuts all 11 switch holes in one operation on one sheet, with no tile seams. | — | $176 + time

Which approach we use is the main question for the TechSpark consult. The case for laser cutting is accuracy — the arm is calibrated to that 50 mm pitch. On cost it is a modest win, not a dramatic one: laser machine time is billed hourly and is not published, so the net saving is likely $30–80 rather than half.

Prices are approximate and exclude tax and shipping; confirm at checkout. Full specification and fabrication plan are in the shared project folder alongside this document.

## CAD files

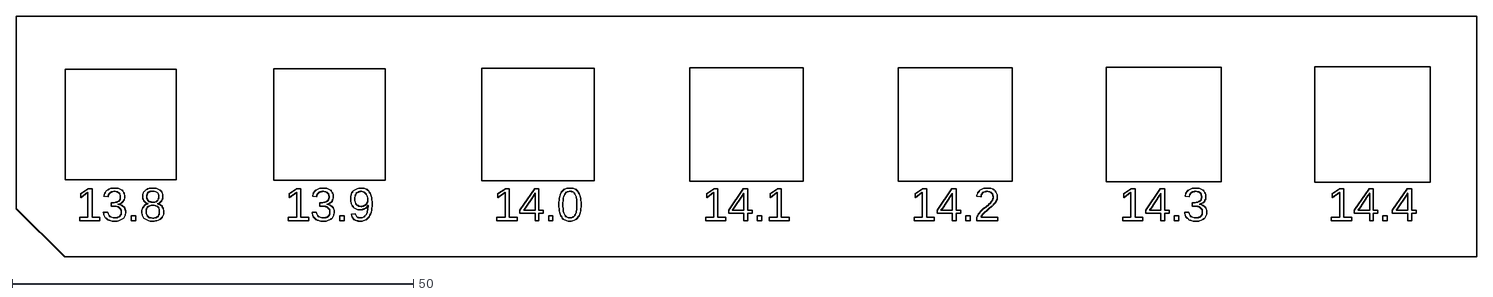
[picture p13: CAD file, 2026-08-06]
physical_piano/exports/COUPON_laser_switch_holes_1.5mm.dxf
182.0 x 30.0

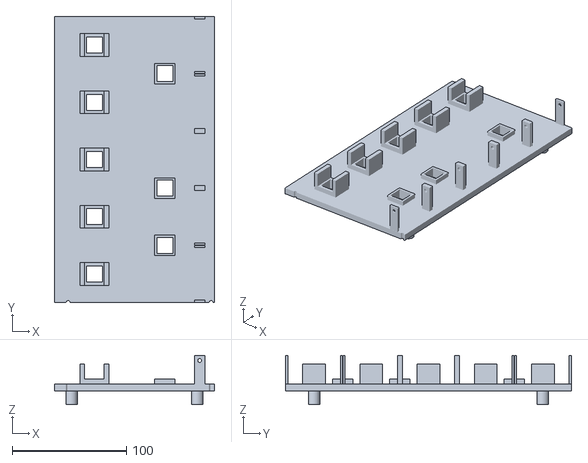
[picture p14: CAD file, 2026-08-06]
physical_piano/exports/PRINT_base_tile_0.stl
140.0 x 250.0 x 43.1

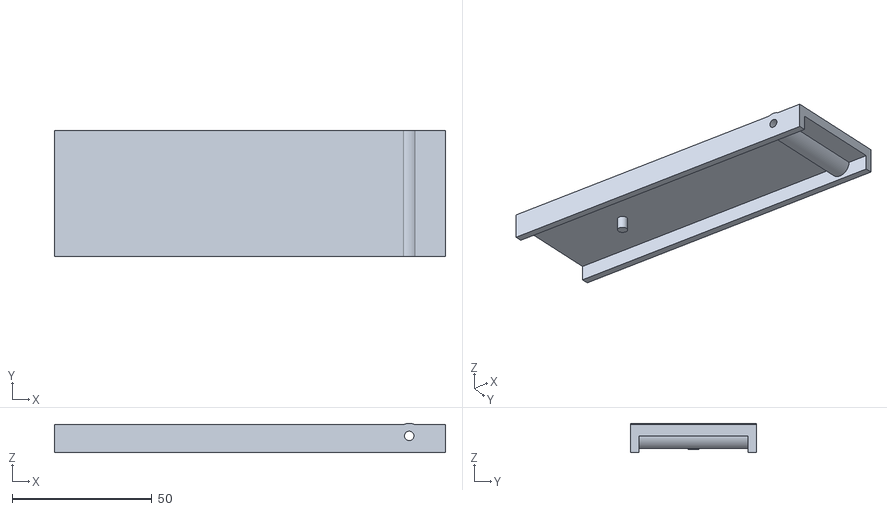
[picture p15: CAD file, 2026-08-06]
physical_piano/exports/PRINT_key_lever_x11.stl
140.0 x 45.0 x 10.5

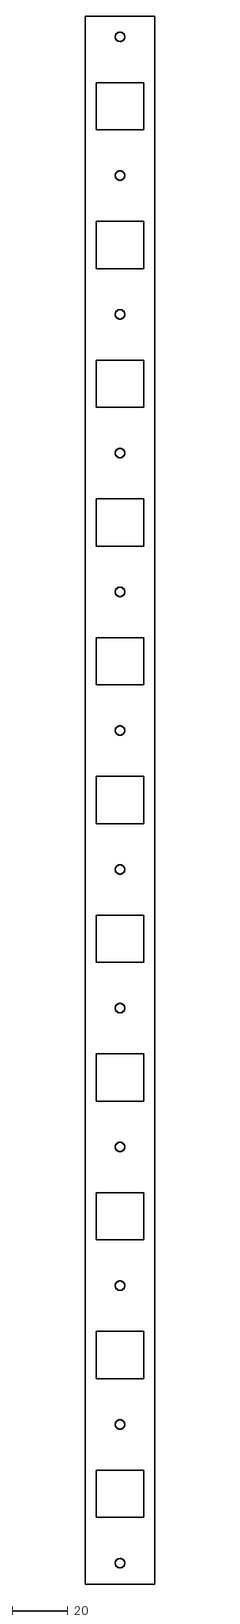
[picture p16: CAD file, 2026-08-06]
physical_piano/exports/LASER_3_stoprail_13.0mm.dxf
25.0 x 565.0

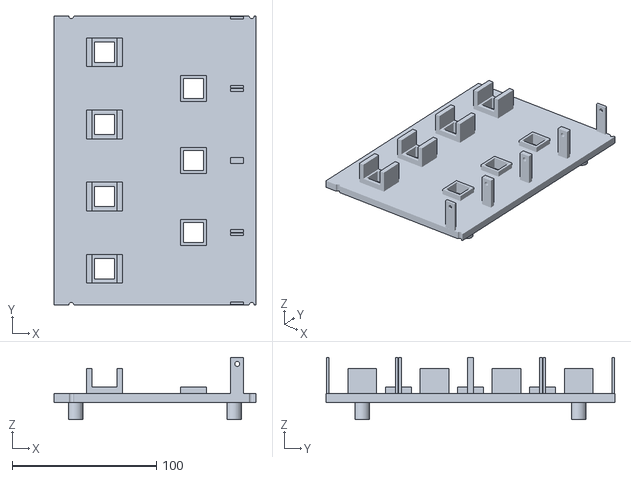
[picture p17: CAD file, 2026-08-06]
physical_piano/exports/PRINT_base_tile_1.stl
140.0 x 200.0 x 43.1

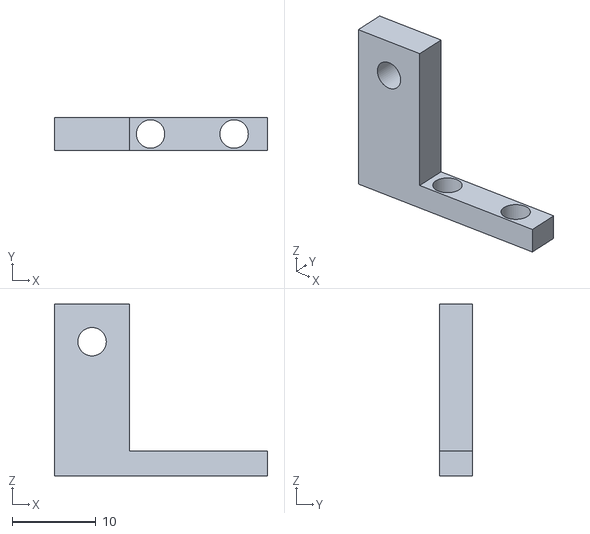
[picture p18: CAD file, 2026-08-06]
physical_piano/exports/PRINT_hinge_bracket_x12.stl
25.5 x 4.00 x 20.6

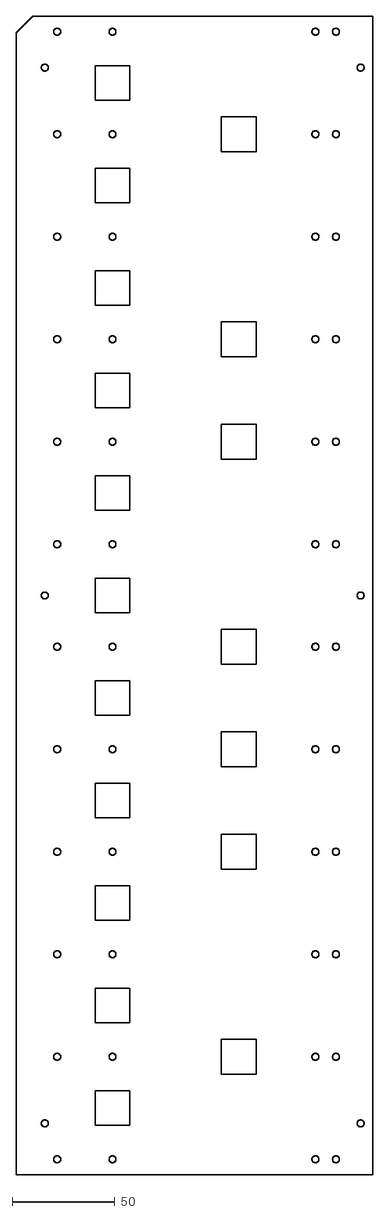
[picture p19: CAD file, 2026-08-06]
physical_piano/exports/LASER_1_structure_9.0mm.dxf
174.0 x 565.0

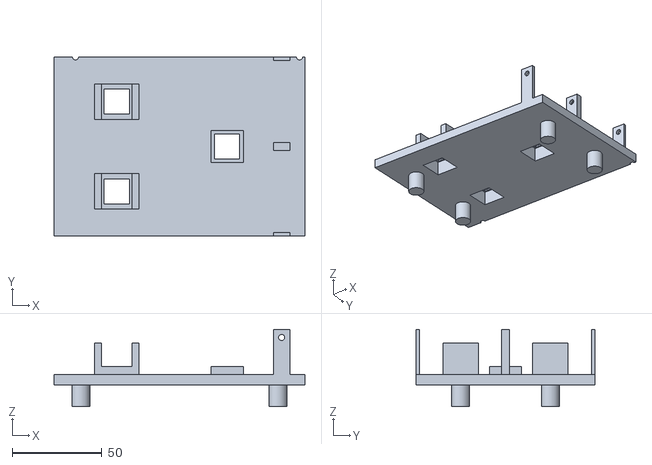
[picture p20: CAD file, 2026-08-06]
physical_piano/exports/PRINT_base_tile_2.stl
140.0 x 100.0 x 43.1

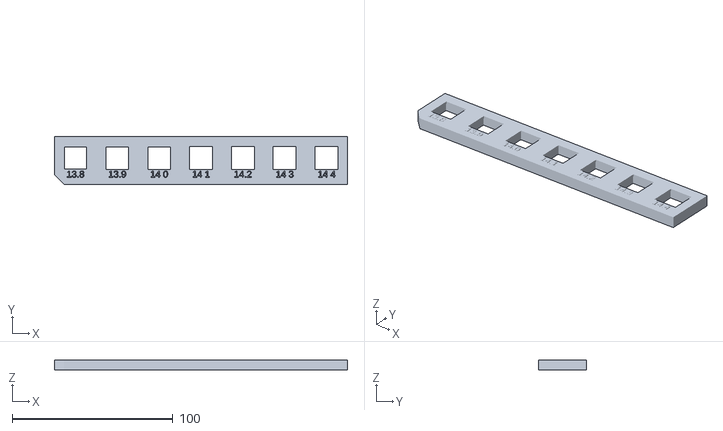
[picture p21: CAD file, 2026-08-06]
physical_piano/exports/COUPON_print_switch_holes.stl
182.0 x 30.0 x 6.50

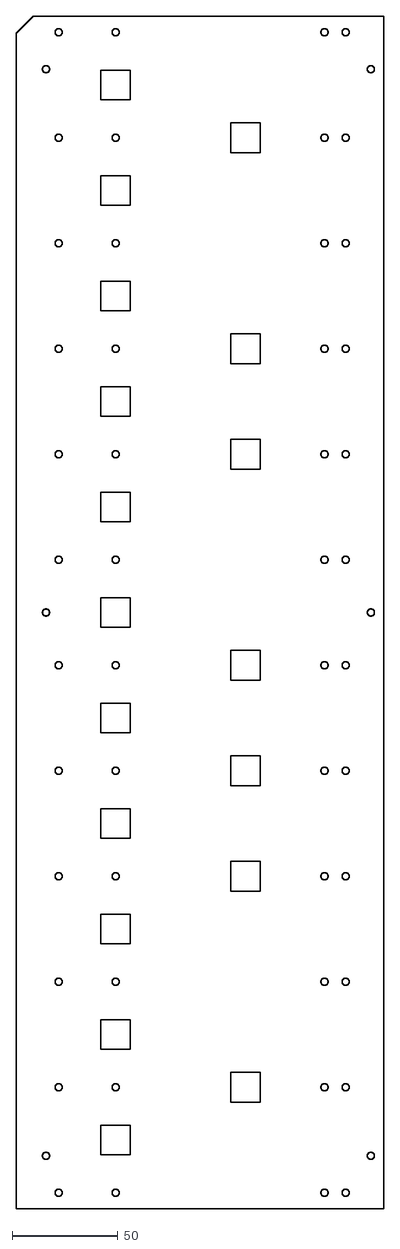
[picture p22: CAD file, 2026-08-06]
physical_piano/exports/LASER_2_switchplate_1.5mm.dxf
174.0 x 565.0

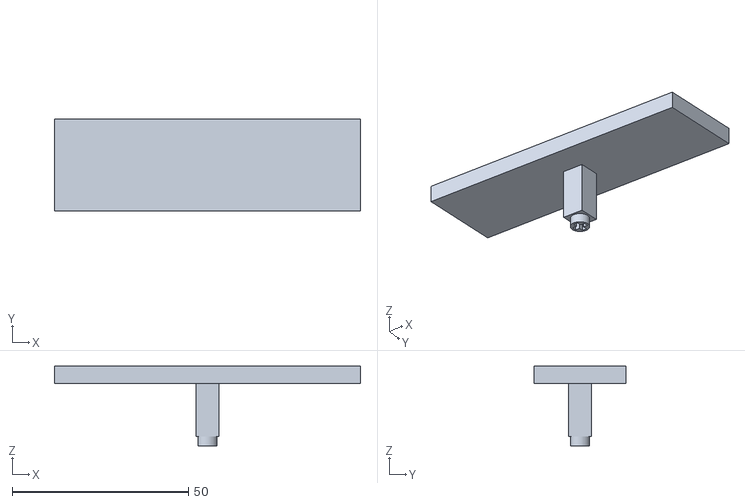
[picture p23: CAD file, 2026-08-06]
physical_piano/exports/PRINT_black_key_x7.stl
86.8 x 26.1 x 22.7

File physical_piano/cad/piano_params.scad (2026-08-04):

// =====================================================================
// piano_params.scad — SINGLE SOURCE OF TRUTH for the physical piano
// =====================================================================
// Both fabrication routes include this file:
//   piano_keys.scad         key levers + black keys (printed in BOTH routes)
//   piano_base_printed.scad all-printed base   \  pick ONE
//   piano_base_laser.scad   laser-cut base     /
//
// Every dimension the two routes must agree on lives HERE and nowhere else.
// This is not housekeeping: pivot_z was previously defined in both files and
// silently drifted to 26.5 in one and 28 in the other, which would have put
// the laser route's hinge pin 1.5 mm too high.
//
// Values marked MEASURED were taken off the physical rig. Do not change them
// without re-measuring.
// =====================================================================

// ---------------- ORIENTATION — read this before changing any layout ----
// x = along the key, 0 at the FRONT edge (the side the fingers press)
// z = up
// y = across the keys
//
// Standing at the front looking at the board: forward = +x, up = +z, so the
// viewer's right = (+x cross +z) = -y. In other words **+y is the viewer's
// LEFT**.
//
// The simulator draws key 0 LEFTMOST, so key 0 must sit at HIGH y. The layout
// functions in the base files handle that. Do NOT "fix" a mirrored-looking
// render by editing black_idx — the board is near enough symmetric that a
// camera on the wrong side swaps the C#D# pair and the F#G#A# triplet, and
// mirroring the list to compensate leaves key 0 at the wrong end, which would
// wire the whole piano backwards.
n_keys    = 11;

// ---------------- Key layout (MEASURED) ----------------
key_w     = 45;      // key width  (mm)
key_len   = 140;     // key length (mm)
key_gap   = 5;       // gap between keys
pitch     = key_w + key_gap;    // 50 mm — what the arm is calibrated to
cap_th    = 4;       // key cap thickness
side_rail = 3;       // cosmetic side skirt

// Fingertip contact point, MEASURED at 35 mm from the key's front edge.
contact_x = 35;

// ---------------- Base / pivot ----------------
base_th   = 6;       // printed base plate thickness
pin_d     = 3.4;     // hinge pin bore (3 mm rod)
pivot_x   = key_len - 13;
clr       = 0.4;     // print clearance for moving mates
// hinge_h and pivot_z are DERIVED further down, from the stop geometry. They
// used to be set here by hand (hinge_h = 20.2), which is what let the press
// the switch actually sees drift 0.3 mm below the nominal mx_press figure —
// see the note on stop_r_lead.

// Knuckle must nearly fill the span between hinge supports or nothing stops
// the key sliding along the pin (see the note in piano_keys.scad).
knuckle_wid    = 45;
knuckle_boss_d = 9;
post_w         = 2;  // hinge post thickness — must fit the 5 mm inter-key gap
post_len       = 9;

// ---------------- MX switch ----------------
// EVERY VALUE IN THIS BLOCK IS READ OFF THE DATASHEET, not estimated:
//   Kailh CPG1511F01S04-1 "Red Shaft", doc KH-PS1706-10 rev B
//   -> ../docs/datasheets/kailh_CPG1511F01S04-1_red.pdf
// The section it comes from is named on each line, so any of these can be
// re-checked in one look. Where a tolerance is given the WORST CASE is used.
// Values that are NOT from the datasheet live in the two blocks below this
// one — do not add estimates here.
//
// s.5  = Profile Dimensions (p.3)
// s.10 = Loading Parameter Specification + Metal Frame Cutout (p.10)

// s.10 "Metal Frame Cutout Dimensions" specifies the PLATE HOLE directly:
// 14.00 +/-0.05 square, corners R0.30 max, in 1.50 +/-0.1 material. So this is
// not inferred from the 13.95 body width — it is the manufacturer's own plate
// spec, and the two agree.
mx_cut       = 14.0;   // s.10  plate cutout, 14.00 +/-0.05
mx_cut_r_max = 0.30;   // s.10  max corner radius of that cutout
mx_plate_th  = 1.5;    // s.10  1.50 +/-0.1 — the thickness the clips grip
mx_travel    = 3.6;    // s.10  TT total travel, 3.60 +/-0.3 -> worst MIN 3.3
mx_travel_tol = 0.3;
mx_actuate   = 1.8;    // s.10  PT pretravel,   1.80 +/-0.3 -> worst MAX 2.1
mx_actuate_tol = 0.3;
// s.10 OT: the travel guaranteed to remain BEYOND the operating point. Since
// TT = PT + OT, this rules out the corner the checks below assume — a switch
// cannot both actuate as late as 2.1 and bottom out as early as 3.3, because
// that would leave OT = 1.2. Designing against both extremes at once is
// therefore conservative, which is deliberate. Do not "recover" the margin.
mx_overtravel = 1.30;  // s.10  OT, minimum
mx_stem_h    = 11.20;  // s.5   stem top above the mounting plate
mx_cross_h   = 3.80;   // s.5   keycap cross post height. This is ALL the
                       //       engagement a keycap can ever get, and it sits
                       //       at the TOP of the stem: the cross spans
                       //       stem_top_z - 3.80 .. stem_top_z. A socket
                       //       placed above stem_top_z grips nothing.
mx_lower_h   = 5.00;   // s.5   lower housing, plate underside downwards
mx_pin_h     = 1.40;   // s.5   pins below that
mx_below_plate = mx_lower_h + mx_pin_h;   // 6.4 below the plate
mx_body_h    = 10.70;  // s.5   whole body, stem and pins excluded
mx_housing_h = mx_body_h - mx_lower_h;    // 5.70 of housing ABOVE the plate

// The top flange is RECTANGULAR, not square, and the switch is lowered between
// the stop shoulders to reach the plate — so it is the WIDE axis the stop
// clearance has to swallow. stop_clear was 15.0, which is under 15.60: the
// switch then only went in turned 90 degrees, with 0.55 mm per side on a
// printed part and nothing in the model saying so. stop_clear is now 17.0 and
// it fits either way round.
mx_housing_w = 15.60;  // s.5  top flange, WIDE axis
mx_housing_d = 13.90;  // s.5  top flange, NARROW axis
mx_clip_w    = 14.87;  // s.5  clips at full width below the plate, +/-0.5, so
                       //      worst case 15.37 — this is what the relief under
                       //      the plate has to clear, not the 13.95 body

// ---------------- OUR CHOICE, not the switch's ----------------------------
mx_riser_h   = 4.5;    // how high we stand the switch plate above the base
                       // plate. Nothing in the datasheet asks for this; it is
                       // set so the stack lands on the shared heights below.

// ---------------- NOT dimensioned on the datasheet — MEASURE THESE ---------
// The datasheet DRAWS all four of these but never dimensions them. The figures
// here were scaled off the s.5 top view against the known 15.60 mm width, so
// treat them as +/-0.15 mm at best. All four gate the black keycap, which is
// the one part that grips the switch rather than merely clearing it.
mx_well_w     = 7.0;   // housing opening the stem slides through. Caps how fat
                       // the black keycap's lower boss may be (blk_boss_w).
mx_shoulder_w = 6.6;   // stem top face — what the keycap seats on
// The cross scales to 4.0 mm across with arms of ~1.27 and ~1.10 mm. It is
// NOT symmetric — that matches the usual MX figures of 1.35 and 1.15 — so a
// square socket has real clearance on one axis and almost none on the other.
mx_cross_w    = 4.0;   // cross span, both arms
mx_cross_th   = 1.35;  // THICKER arm. The thin one is ~1.15; sizing the socket
                       // to the thick arm is what makes it fit both.

// ---------------- Stops ----------------
// The hard bottom stop for the white keys. Both routes build it: the printed
// route as shoulders either side of the socket, the laser route as a rail
// across the board. Sharing the numbers here is what keeps the two agreeing.
stop_clear = 17.0;   // square hole at each key, clears the 15.60 housing
stop_width = 4.0;    // stop material either side of that hole
// A GIVEN, not a free choice: it is the laser stack, 9.0 + 1.5 + 13.0 mm of
// stock. pivot_z is derived from it rather than the other way round.
stop_top   = 23.5;

// ---------------- Motion ----------------
rest_gap  = 0;     // key RESTS on the stem; a gap is physically impossible
// Chosen as the midpoint between the worst-case actuation depth (2.1) and the
// worst-case bottom-out depth (3.3), so it has 0.6 mm of margin either way.
// This is the press AT THE PLUNGER, which is what the switch sees.
mx_press  = 2.7;

// ---------------- Self-actuation figures ----------------
key_mass_g    = 16;   // printed key lever, ~20% infill
// RF (return force) is specified as a MINIMUM of 15 gf. The datasheet gives no
// preload figure, so 15 gf is the only guaranteed force holding the key up —
// design against it, not against a typical value.
mx_preload_gf = 15;
mx_act_gf     = 45;   // OF operating force, 45 +/-10 gf
com_arm       = 57;   // key centre of mass from the pivot
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

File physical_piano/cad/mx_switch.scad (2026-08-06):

// =====================================================================
// mx_switch.scad — a to-scale MX switch, and the fit checks that use it
// =====================================================================
// NOTHING HERE IS FABRICATED. This file exists so the switch can be put in
// the board and looked at, instead of the fit being argued from numbers.
//
// It earns its place: the black keycap's cross socket was modelled 3.8 mm
// ABOVE the stem's cross for several revisions. Every dimension involved was
// individually correct and the sanity checks all passed, because nothing in
// the project drew the switch. Dropping this model in makes it obvious in one
// render.
//
//   mode "switch"      the switch on its own
//   mode "white"       section through a white key position   <- the stop fit
//   mode "black"       section through a black key position   <- the socket fit
//   mode "fit_slice"   plan cut at the housing, both rotations side by side
//
// For a section, set mode then look at it from the front (Ctrl+5 / View >
// Front). `press` drives the stem down so travel can be checked, not just
// the rest position.
//
// SOURCE: Kailh CPG1511F01S04-1 "Red Shaft", doc KH-PS1706-10 rev B, section 5
// "Profile Dimensions" -> ../docs/datasheets/kailh_CPG1511F01S04-1_red.pdf
// Every figure below is read off that drawing EXCEPT the two marked MEASURED
// OFF THE DRAWING, which the datasheet does not dimension.
// =====================================================================

include <piano_params.scad>
use     <piano_keys.scad>
use     <piano_base_printed.scad>

$fn = 32;

// ---------------------------------------------------------------------
// The switch
// ---------------------------------------------------------------------
// Origin at the CENTRE OF THE PLATE HOLE, z = 0 at the PLATE TOP — the same
// datum the datasheet dimensions from. So it is placed with
//   translate([x, y, mx_plate_z]) mx_switch();
//
// rot = 0 puts the wide (mx_housing_w) axis along x; rot = 90 puts the narrow
// (mx_housing_d) axis along x. With stop_clear at 17.0 both now fit — at the
// old 15.0 only rot = 90 did, which is what this model was written to catch.
module mx_switch(press = 0, rot = 0) {
    shaft_h = mx_stem_h - mx_cross_h - mx_housing_h;   // 1.70 of bare stem
    rotate([0, 0, rot]) {
        // ---- fixed: housing, clips, pins ----
        color("#3F4756") {
            translate([0, 0, mx_housing_h/2])
                cube([mx_housing_w, mx_housing_d, mx_housing_h], center = true);
            translate([0, 0, -mx_lower_h/2])
                cube([mx_cut - 0.05, mx_cut - 0.05, mx_lower_h], center = true);
            // clips, at their widest — this is what the relief below the plate
            // has to clear, not the 13.95 body
            translate([0, 0, -mx_lower_h + 0.6])
                cube([mx_clip_w, mx_cut - 0.05, 1.2], center = true);
        }
        color("#8A8F98") for (s = [-1, 1])
            translate([s*3, 2, -mx_lower_h - mx_pin_h/2])
                cube([1, 0.4, mx_pin_h], center = true);
        // ---- moving: stem shoulder + cross ----
        color("#B4553F") translate([0, 0, -press]) {
            translate([0, 0, mx_housing_h + shaft_h/2])
                cube([mx_shoulder_w, mx_shoulder_w, shaft_h], center = true);
            for (r = [0, 90]) rotate([0, 0, r])
                translate([0, 0, mx_stem_h - mx_cross_h/2])
                    cube([mx_mount_cross - 0.2, mx_mount_th - 0.15, mx_cross_h],
                         center = true);
        }
    }
}

// ---------------------------------------------------------------------
// Checks
// ---------------------------------------------------------------------
mode    = "white";
press   = 0;      // 0 = at rest. Try mx_press for a white key at its stop,
                  // or blk_travel for a black key bottomed out.
sw_rot  = 0;
section = true;   // Cut away the NEAR half (y < 0). Leave this ON for the front
                  // view: the key lever's side skirts hang 6 mm below the cap
                  // and sit between the camera and everything worth looking at.
                  // Uncut, a pressed key shows a skirt crossing the stop
                  // shoulder, which reads as contact when the two are 12 mm
                  // apart in y and never touch.

// `plane` is the y the section is taken on — it has to follow the part being
// checked. A white key sits at y = 0, a black key at y = -pitch/2, and a cut
// fixed at 0 simply deletes the black key instead of sectioning it.
module cut(plane = 0) {
    if (section)
        difference() {
            children();
            translate([-60, plane - 90, -40]) cube([320, 90, 140]);
        }
    else children();
}

// A white key position: switch between the stop shoulders, plunger on the
// stem. What to look for: the housing clear of both shoulders, and the cap
// underside reaching the shoulder tops exactly as the plunger reaches mx_press.
//
// The key ROTATES about the pin, it does not drop — which is the whole reason
// the stops ground it early. `press` is the travel at the PLUNGER, so the
// angle comes from plunger_arm and every other point on the cap moves by its
// own radius. Set press = mx_press to see it land.
module check_white() {
    ang = asin(press / plunger_arm);
    base_cell(-1);
    color("#E8E8E8")
        translate([pivot_x, 0, pivot_z])
            rotate([0, -ang, 0])
                translate([-pivot_x, 0, -pivot_z]) key_lever(-1);
    translate([contact_x, 0, mx_plate_z]) mx_switch(press, sw_rot);
}

// A black key position. This one DOES travel straight down — no lever — so the
// cap moves with the stem. What to look for: the keycap's socket SWALLOWING
// the cross rather than perching on top of it, and the slim boss — not the
// full-width post — being the only thing near the housing at full travel.
// Set press = blk_travel for the bottomed-out case.
module check_black() {
    base_cell(0);
    color("#E8E8E8") key_lever(0);
    color("#111111") translate([0, -pitch/2, -press]) black_key();
    translate([blk_switch_x, -pitch/2, mx_plate_z]) mx_switch(press, sw_rot);
}

// Plan cut level with the housing, showing both rotations. Separate islands
// mean the switch drops in; one merged blob means it fouls the shoulders.
module check_fit_slice() {
    z_cut = (mx_plate_z + housing_top_z) / 2;
    for (i = [0, 1])
        translate([0, i * 60, 0])
            projection(cut = true) translate([0, 0, -z_cut]) {
                base_cell(-1);
                translate([contact_x, 0, mx_plate_z]) mx_switch(0, i * 90);
            }
}

if      (mode == "switch")    mx_switch(press, sw_rot);
else if (mode == "white")     cut(0)         check_white();
else if (mode == "black")     cut(-pitch/2)  check_black();
else if (mode == "fit_slice") check_fit_slice();

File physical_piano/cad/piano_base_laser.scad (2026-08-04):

// =====================================================================
// piano_base_laser.scad — the LASER ROUTE for the keybed base
// =====================================================================
// >>> THIS FILE IS NOT ALL LASER-CUT, AND IT IS NOT THE WHOLE BOARD. <<<
//
// It is named for the ROUTE, not the process. What is in here:
//
//   mode "2d_struct"        LASER  9.0 mm sheet   x1
//   mode "2d_switch_plate"  LASER  1.5 mm sheet   x1
//   mode "2d_stop_rail"     LASER 13.0 mm sheet   x1
//   mode "hinge_block"      PRINT  small bracket  x12   <-- printed, not lasered
//
// And what is NOT in here, but is still needed to build this route:
//
//   key lever   x11   -> piano_keys.scad, mode "key"     (printed)
//   black key   x7    -> piano_keys.scad, mode "black"   (printed)
//   3 mm pin rod ~570 mm, and 6 x 12 mm standoffs        (bought)
//
// So the laser route = 3 laser parts + 30 printed parts across TWO files.
// piano_base_printed.scad is the OTHER route — do not build both.
// See ../TECHSPARK_PLAN.md for the full parts manifest.
//
// WHY: all 11 switch positions get cut in ONE operation on ONE sheet, so the
// 50 mm pitch the arm is calibrated to has no tile seams to drift across.
// (The printed base must be split into 3 tiles for a 254 mm print bed.)
//
// LAYER STACK (z measured from the board's underside):
//
//   z=23.5 ┌──────────────┐  stop rail    13.0 mm  <- key cap lands HERE
//   z=10.5 ├──────────────┤  switch plate  1.5 mm  <- MX clips into 14 mm hole
//   z=9.0  ├──────────────┤  structure     9.0 mm  <- feet, brackets, bolting
//   z=0    └──────────────┘  board underside (on 12 mm standoffs)
//
// Only TWO sheets: an earlier version had a third "spacer" layer, but once the
// structural layer was drilled through under every switch the spacer had no
// remaining job and was removed.
//
// The thicknesses are chosen so the switch plate top lands at mx_plate_z and
// the stop rail top at stop_top — both defined in piano_params.scad — so this
// route and the printed route are geometrically interchangeable.
//
// EXPORT: set mode to a "2d_*" value, press F6, then File > Export > Export as
// DXF (or SVG). Each 2D profile is a flat cut path. The 3D modes are for
// visual checking only.
// =====================================================================

include <piano_params.scad>
use     <piano_keys.scad>      // key_lever() / black_key() for previews

$fn = 48;

// Side margin so the OUTERMOST hinge brackets land on material. Without it the
// boundary positions at each end fall exactly on the board edge (or past it).
margin_side = 10;
board_w   = n_keys * pitch - key_gap + 2 * margin_side;   // 545 + 20 = 565 mm

// ---------------- Layer thicknesses (set the critical heights) ----------
// Only TWO layers below the stop rail. An earlier version had a separate
// "spacer" to clear the switch body, but once the structural layer was drilled
// through under every switch it did the same job — so the spacer was doing
// nothing and has been merged away.
t_struct  = 9.0;    // structure, feet, all bolting. Standard stock, stiff over
                    // 565 mm, and far easier to laser than 12 mm.
t_plate   = 1.5;    // MX switches CLIP into 1.5 mm — mandatory, cannot be thicker
t_stop    = 13.0;

// ---------------- Derived heights ----------
z_plate   = t_struct;
z_plate_t = z_plate + t_plate;
z_stop_t  = z_plate_t + t_stop;

echo(str("switch plate top z = ", z_plate_t, "  (shared mx_plate_z = ", mx_plate_z, ")"));
echo(str("stop rail top z    = ", z_stop_t,  "  (shared stop_top   = ", stop_top, ")"));
echo(str("below-plate clearance = ", t_struct, " mm in-board (need ", mx_below_plate,
         "), plus ", foot_h, " mm of open air under the feet"));
echo(str("KEY TOP above the TABLE = ", key_top_z + foot_h,
         " mm — the feet raise everything, so raise the arm to match"));

// These compare the laser stack against the SHARED values, so the two routes
// can never silently drift apart again.
if (z_plate_t != mx_plate_z)
    echo("*** WARNING: laser stack puts the switch plate at ", z_plate_t,
         " but piano_params.scad says ", mx_plate_z, " — adjust t_struct/t_plate ***");
if (z_stop_t != stop_top)
    echo("*** WARNING: laser stop rail top is ", z_stop_t,
         " but piano_params.scad says ", stop_top, " — adjust t_stop ***");
if (t_struct < mx_below_plate)
    echo("*** NOTE: switch pins reach past the board underside — fine, the feet ",
         "give clearance, but keep foot_h above ", mx_below_plate - t_struct, " mm ***");

// ---------------- Board footprint ----------------
margin_front = 12;        // material ahead of the key front edge
margin_rear  = 22;        // material behind the pivot, carries hinge blocks
board_l      = key_len + margin_front + margin_rear;   // 174 mm

// ---------------- Feature sizes ----------------
sw_clear   = 17.0;        // clearance hole for the switch BODY below the plate
// stop_clear MOVED to piano_params.scad. The printed route's stop shoulders
// need exactly the same number, and a second copy here is precisely how
// pivot_z drifted between the two routes once before. The hole stays square,
// not round: a round hole would have to be 22 mm across to pass the housing's
// diagonal, which would leave the rail far too thin.
bolt_d     = 3.4;         // M3 clearance

// Stop rail runs ACROSS all keys at the contact point. The key cap lands on
// its top face; the plunger passes through stop_clear to reach the stem.
//
// The rail is exactly as wide as the printed route's shoulders — the clearance
// hole plus stop_width either side — so BOTH routes bind at the same radius
// from the pivot (stop_r_lead) and give the same press. It used to run to
// contact_x +/- 15, reaching 2.5 mm further forward than the printed shoulders
// and grounding the key earlier still.
stop_x0    = contact_x - (stop_clear/2 + stop_width);
stop_x1    = contact_x + (stop_clear/2 + stop_width);

hinge_post_len = 9;             // bracket length along x
hinge_post_w   = 4;             // bracket thickness — must fit the 5 mm gap
// Both bracket bolts sit BEHIND the pivot. A forward bolt would land at
// x ~118, inside the black key web's 62-120 span, and the web shares this gap.
hinge_bolt_x1  = pivot_x + 7;
hinge_bolt_x2  = pivot_x + 17;

// Black key webs drop through slots cut at the black boundaries. The POSITIONS
// come from black_idx in piano_params.scad — this file must never keep its own
// copy of that list, or the two can drift the way pivot_z once did.

// Hinge brackets sit ON THE BOUNDARIES between keys (in the 5 mm gaps), not
// under the keys — a bracket under a key would foul the cap. One bracket per
// boundary, including the two outer edges, so 12 across the board. They all
// carry ONE continuous pin rod, which also guarantees every pivot is collinear.
n_hinge = n_keys + 1;
// Negated to match key_y above — boundary_y(b+1) stays the midpoint between
// key b and key b+1 either way.
function boundary_y(j) = -(j - n_keys / 2) * pitch;   // j = 0 .. n_keys

// Key centre y for key index i, board centred on y=0.
// NEGATED so key 0 lands at HIGH y = the viewer's LEFT, matching the simulator.
// See the orientation note at the top of piano_params.scad.
function key_y(i) = -(i - (n_keys - 1) / 2) * pitch;
// x is measured from the key's FRONT edge; board local x adds the margin
function bx(x) = x + margin_front;
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

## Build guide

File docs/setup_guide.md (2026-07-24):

# BCI Robot Interface — Setup Guide

This guide covers everything needed to set up the BCI-controlled robotic arm and hand interface on a Windows PC.

---

## System Overview

The interface connects a Kinova Gen3 robotic arm and an Allegro Hand V4 to a BCI2000 brain-computer interface system running the piano typing task.

For the piano task, BCI2000 streams **all** control data as a single combined
record on **one** UDP port (5005) at **8 Hz**. Because two processes cannot
reliably share a UDP port, a dispatcher owns 5005 and forwards the record to the
two controllers on separate local ports:

```
BCI2000 (Windows)
  └── UDP 5005 → bci2000_dispatcher.py ┬── UDP 5006 → arm_controller.py → Kortex API (Ethernet) → Kinova Gen3 Arm
                                        └── UDP 5007 → myAllegroHand.exe → PCAN-USB (CAN bus)     → Allegro Hand V4
```

**Stream (confirmed from `SigGen_Piano_vel.bat` and `Piano_Application_vel.py`):**
- Single port 5005, single tab-separated record, 8 Hz (SamplingRate=1024Hz, SampleBlockSize=128).
- The arm is **1-D** (horizontal slide along the keys). The fingers handle key presses; the arm does not move vertically.

---

## Hardware Requirements

- Kinova Gen3 robotic arm
- Allegro Hand V4 (right hand configuration)
- PEAK PCAN-USB CAN adapter
- Windows 11 PC
- Ethernet cable (for arm connection)
- CAN bus cable (for hand connection, included with Allegro Hand)

---

## Network Configuration

The Kinova arm communicates over Ethernet. Configure the PC's Ethernet adapter:

- **Arm IP address:** `192.168.1.10`
- **PC Ethernet adapter IP:** `192.168.1.11`
- **Subnet mask:** `255.255.255.0`

To verify connectivity after configuring, run:
```
ping 192.168.1.10
```
You should receive replies with no packet loss.

---

## Software Requirements

### 1. Python 3.9

The arm controller requires Python 3.9 specifically due to a compatibility issue between the Kortex API and newer Python versions (`collections.MutableMapping` was removed in Python 3.10).

Download from: https://www.python.org/downloads/release/python-3913/

During installation, check **"Add python.exe to PATH"**.

Verify installation:
```
py -3.9 --version
```

### 2. Kortex API (Python)

The Kortex API is distributed as a `.whl` file — it is not available on PyPI. The file `kortex_api-2.6.0.post3-py3-none-any.whl` is included in the `arm/` folder of this repository.

Set up a dedicated virtual environment:
```
py -3.9 -m venv kortex_env39
kortex_env39\Scripts\activate
pip install arm\kortex_api-2.6.0.post3-py3-none-any.whl
pip install numpy
```

**Important:** Always activate `kortex_env39` before running the arm controller. Do not use any other Python environment for arm control, as the Kortex API will not be available.

### 3. PEAK PCAN-USB Driver

Download **Device driver setup 5.x for Windows** from:
https://www.peak-system.com/PCAN-USB.199.0.html

During installation, keep the default options — **CAN device drivers** and **PCAN-Basic API** should both be selected. You may need to reboot after installation.

After installation, verify the driver installed correctly:
- Open Device Manager (Start → search "Device Manager")
- Look for the PCAN-USB adapter under "CAN-Hardware"

### 4. Visual Studio (Community Edition)

Required to build the hand controller C++ project.

Download from: https://visualstudio.microsoft.com/downloads/

During installation, select the **"Desktop development with C++"** workload.

**Note:** Visual Studio (full IDE) is different from VS Code (lightweight editor). Both may be used — VS Code for Python scripts, Visual Studio for the C++ hand controller.

---

## Building the Hand Controller

### Step 1 — Open the project

Open Visual Studio and load:
```
hand\myAllegroHand.sln
```

A migration report may appear in your browser — this is harmless. The project was originally created in Visual Studio 2010 and will be automatically updated.

### Step 2 — Set configuration

At the top of Visual Studio, set the configuration dropdown to **Peak Debug** and platform to **Win32**.

### Step 3 — Set DLL path

Right-click **myAllegroHand** in the Solution Explorer → **Properties**.

Navigate to **Configuration Properties → Debugging** and set the **Environment** field to:
```
PATH=C:\Program Files\PEAK-System\PEAK-Drivers 5\;%PATH%
```

Click Apply then OK.

### Step 4 — Build

Go to **Build → Build Clean Solution → Build Solution**.

The output should show:
```
Build: 1 succeeded, 0 failed, 0 skipped
```

The compiled executable will be at:
```
hand\Peak Debug\myAllegroHand.exe
```

### Step 5 — Copy DLL

Copy `libBHand.dll` from `hand\lib\BHand\` to `hand\Peak Debug\`:
```
copy "hand\lib\BHand\libBHand.dll" "hand\Peak Debug\"
```

---

## Running the Interface

Run each component in a separate terminal window. All terminals running Python scripts must have `kortex_env39` activated. **Start the dispatcher first** — it owns port 5005, and the controllers listen on the ports it forwards to.

### Step 1 — Connect hardware

1. Connect the Kinova arm to the PC via Ethernet
2. Power off the Allegro Hand
3. Connect the PCAN-USB adapter to the PC
4. Connect the CAN cable from the PCAN-USB adapter to the Allegro Hand
5. Power on the Allegro Hand

### Step 2 — Start the dispatcher

In a terminal (a plain Python is fine — the dispatcher has no Kortex dependency):
```
python dispatcher\bci2000_dispatcher.py
```
It should print that it is listening on `127.0.0.1:5005` and forwarding to 5006 (arm) and 5007 (hand).

### Step 3 — Start the hand controller

Run `myAllegroHand.exe` from Visual Studio by pressing **F5**, or directly from the command line:
```
"hand\Peak Debug\myAllegroHand.exe"
```

The console should show the CAN channel opening, hardware info, and then:
```
Listening for piano finger data on UDP port 5007 (via dispatcher)...
```

The hand will move to its resting pose on startup.

### Step 4 — Start the arm controller

In a new terminal with `kortex_env39` activated:
```
cd arm
kortex_env39\Scripts\activate
python arm_controller.py --ip 192.168.1.10
```

The arm will move to its home position (hand over the center key), then track `ArmPred_X`.

### Step 5 — Run BCI2000 or the simulator

For real experiments, launch BCI2000 with `BCI2000 Piano\SigGen_Piano_vel.bat`.

For testing without BCI2000, use the simulator (see next section).

---

## Using the Simulator

The simulator replicates the real piano stream (single port 5005, 8 Hz, BCI2000 watch-packet framing) for testing without a real BCI2000 session. It talks to the **dispatcher**, so start the dispatcher (and, optionally, the controllers) first. Run it in its own terminal:

```
cd simulator
python bci_arm_hand_simulator.py
```

### Key commands

| Command | Description |
|---|---|
| `trial <key> <finger>` | Full trial: slide arm to key window (1–9), then press finger (0–2) |
| `demo [n]` | Run n random trials (default 4) |
| `key <index>` | Slide the arm so the middle finger is over key index 1–9 |
| `armx <px>` | Set raw arm position directly, −420..420 px (0 = center key 5) |
| `press <0\|1\|2>` | Fire a single finger press (0=left, 1=center, 2=right) |
| `home` | Recenter the arm over the center key, lift the finger |
| `status` | Show current stream state |

**Recommended first test:** `demo 4` with the dispatcher (and both controllers) running — this is the closest simulation of a real piano session.

**Finger vs. key:** `CopilotFingerPred` 0/1/2 presses the key to the left of / under / right of the arm's middle finger, so the pressed key = `ArmCurrentIndex + finger − 1`.

---

## Packet Formats

### Piano stream (BCI2000 → UDP port 5005, 8 Hz)

BCI2000's `ADD WATCH` sends one tab-separated record per packet, framed with a
leading frame counter and a trailing tab + CRLF:
```
<counter>  CurrentTrial  InnerTrialCount  ArmPred_X  FingerMovePhase  CopilotFingerPred  targetKeyIndex  pressedKeyIndex  ArmCurrentIndex  <CRLF>
```

| Field | Range | Meaning |
|---|---|---|
| `CurrentTrial` | 1–5 | block number |
| `InnerTrialCount` | 0+ | step within the block |
| `ArmPred_X` | 32347–33187 | arm horizontal position, = px + 32767 offset (px ∈ [−420, 420]) |
| `FingerMovePhase` | 0/1 | **edge-triggered** press pulse — press on the 0→1 transition |
| `CopilotFingerPred` | 0/1/2 | finger to press: left / center / right |
| `targetKeyIndex` | 2–8 | intended note key (C–B) |
| `pressedKeyIndex` | 0–10 | key actually pressed (= `ArmCurrentIndex + CopilotFingerPred − 1`) |
| `ArmCurrentIndex` | 1–9 | key the middle finger is currently over |

### Forwarded record (dispatcher → arm 5006 / hand 5007)

The dispatcher drops the leading counter and trailing junk (it splits on tabs,
discards empty tokens, and keeps the last 8 fields — robust to the counter's
digit count) and re-sends the same 8 fields, tab-separated, to both controllers:
```
CurrentTrial  InnerTrialCount  ArmPred_X  FingerMovePhase  CopilotFingerPred  targetKeyIndex  pressedKeyIndex  ArmCurrentIndex
```
- **Arm controller** uses `ArmPred_X` only.
- **Hand controller** uses `FingerMovePhase` (rising edge) and `CopilotFingerPred`.

> **Note on the press pulse:** `FingerMovePhase` is true only during the
> `FingerHold` phase (`ResultHoldTime`, ~100 ms in the loaded `.prm`). At 8 Hz
> (~125 ms/packet) that is captured in one packet, occasionally zero. If presses
> are ever missed on the real system, raise `ResultHoldTime` in the parameters.

---

## Key Configuration Values

### Arm controller (`arm/arm_controller.py`)
```python
HOME_X  =  0.472   # meters — world X, ALONG the key row; hand over the CENTER key
HOME_Y  = -0.516   # meters — depth (perpendicular to the key row)
HOME_Z  =  0.115   # meters
DEADZONE = 0.005   # meters — arm stops moving within this of target (~0.1 key)
KP        = 3.0    # 1/s — proportional gain: velocity = KP * position_error
MAX_SPEED = 0.4    # m/s — safety speed cap
ARM_Y_SIGN = -1    # flip if the arm slides the wrong way along the keys
```

Calibration (derived from `Piano_Application_vel.py`, do not change unless the
BCI2000 geometry changes): `105` px per key, key width `0.0508 m` (2 in), so
`M_PER_PX = 0.0508 / 105`. `ArmPred_X` range ±420 px = ±4 keys = ±0.2032 m.

The arm tracks the key row along its **world X** axis (base frame); world Y is
depth. The servo commands a base-frame X velocity proportional to the position
error (`KP`), so it is independent of tool orientation.

To update the home position:
1. In the Kinova web app (`192.168.1.10`), jog the arm along X to find its
   reachable min and max at the keyboard's depth/height, then home at the
   **midpoint** so the ±4-key span (±0.2032 m) fits with margin. The arm has
   poor reach toward its own base — if one side runs out of room, slide the
   keyboard away from the base and re-center. (`arm_controller.py` will show a
   persistent position error with velocity pinned at `MAX_SPEED` if a target is
   beyond reach.)
2. Jog so the middle finger sits over the center key, record the end effector
   coordinates, and update `HOME_*` (values are in meters; the web app shows cm).
3. Confirm `ARM_Y_SIGN` by sending `key 6` then `key 4` from the simulator:
   higher key indices must track toward the hand's ring-finger side (the right
   finger presses key index+1).

### Hand controller (`hand/RockScissorsPaper.cpp`)
```cpp
// CopilotFingerPred 0/1/2 -> which Allegro finger presses. [0] is the proximal
// (MCP) knuckle joint that drives the press.
static const int fingerJoints[3][2] = { {1,3}, {5,7}, {9,11} }; // index / middle / ring
static double press_flexion = 0.80;   // radians the proximal knuckle rotates to press
```
```cpp
// hand/myAllegroHand.cpp
#define PRESS_HOLD_MS   400           // how long to hold a press before lifting
```
The press is driven almost entirely by the **proximal (MCP) knuckle** joint:
`initpos` is calibrated so the fingertips already point straight down at the
keys, and `PressFinger()` rotates just that one joint to drive the rigid
fingertip down onto the key. Confirm `fingerJoints` matches how the three
playing fingers are physically mounted (finger 2 / ring presses key index+1),
and tune `press_flexion` / `PRESS_HOLD_MS` so a press depresses the key cleanly
without jamming. The three playing fingers share one identical posture in
`initpos`, so only one set of joint values needs tuning.

The `initpos` array defines the hand's resting position (fingers hovering over the keys). If the hand needs to be recalibrated, add the following print block to `MainLoop()` in `myAllegroHand.cpp` immediately after the `MotionReset()` call, rebuild, and record the printed values to update `initpos` and `position` in `RockScissorsPaper.cpp`:

```cpp
MotionReset();

// Temporary calibration block — remove after recording values
Sleep(3000);  // wait for hand to reach its resting pose
printf("Resting pose joint values:\n");
for (int i = 0; i < 16; i++)
{
    printf("q[%d] = %.4f\n", i, q[i]);
}
```

---

## Troubleshooting

**Arm aborts immediately on startup**
The arm's current position is too far from the home position defined in `arm_controller.py`. Jog the arm closer to home using the web app at `192.168.1.10`, or update the home position constants.

**Hand controller crashes with `libBHand.dll not found`**
Copy `libBHand.dll` from `hand\lib\BHand\` to `hand\Peak Debug\`.

**Kortex API import errors / yellow squiggles in VS Code**
Make sure `kortex_env39` is activated and VS Code is using the `kortex_env39` interpreter. The Kortex API requires Python 3.9 — it will not work with Python 3.10 or later.

**CAN channel fails to open**
Check that the PCAN-USB adapter is connected and the driver is installed. Verify in Device Manager that the adapter appears under "CAN-Hardware" without errors.

**Hand jitter when not moving**
Increase `DEADZONE` in `arm_controller.py`. The default 2cm should prevent jitter but may need tuning based on your setup.

**Build errors after modifying `myAllegroHand.cpp`**
Make sure `#include <winsock2.h>` appears before `#include "windows.h"` — reversing this order causes hundreds of socket redefinition errors.

---

## File Reference

```
BCI_RobotInterface/
├── arm/
│   ├── arm_controller.py          Arm control (1-D key tracking, port 5006)
│   ├── utilities.py               Kinova connection helper (unmodified)
│   └── kortex_api-2.6.0.post3-py3-none-any.whl   Kortex API installer
├── hand/
│   ├── myAllegroHand.cpp          Hand control (edge-triggered press, port 5007)
│   ├── RockScissorsPaper.cpp      Finger press / reset functions
│   ├── RockScissorsPaper.h        Header
│   └── ...                        Remaining project files (unmodified)
├── dispatcher/
│   └── bci2000_dispatcher.py      Owns port 5005, fans out to arm + hand
├── simulator/
│   └── bci_arm_hand_simulator.py  Piano-stream simulator for testing
├── BCI2000 Piano/                 Piano-task BCI2000 reference files
│   ├── SigGen_Piano_vel.bat       Launches the piano task
│   ├── BioSemi_Piano.prm          Piano parameters
│   └── Piano_Application_vel.py    App module (authoritative field definitions)
└── docs/
    └── setup_guide.md             This document
```

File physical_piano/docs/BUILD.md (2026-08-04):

# Physical Piano — Build Spec

Physical 11-key piano for the BCI arm/hand piano task. Replaces the toy
mockup already validated on the physical arm/hand interface (11 keys,
4.5 cm wide with 0.5 cm gaps, one key-step = 5.0 cm, confirmed working).

The layout, key count, and note mapping intentionally match the BCI2000
simulator so the physical instrument behaves and sounds like
[`Piano_Application_vel.py`](../../BCI2000%20Piano/Piano_Application_vel.py).

## Geometry (confirmed against hardware)

| Property | Value |
|---|---|
| Keys | 11, white, in a row |
| Key width | 4.5 cm (1.77″) |
| Gap between keys | 0.5 cm (0.20″) |
| Key length (depth)  | 14 cm (5.5″) |
| Key pitch (center→center) | **5.0 cm (1.97″)** — equals the arm's one key-step |
| Total keyboard width | 11 × 4.5 cm + 10 × 0.5 cm = **54.5 cm (21.5″)** (+ frame margin) |

The 5.0 cm pitch is the load-bearing number: each physical key center must sit
exactly 5.0 cm from the next (4.5 cm key + 0.5 cm gap) so the arm's key-step
lines up. This pitch is ~1.97″, which is why the earlier "2-inch key-step"
calibration still worked — only the key-width/gap split was mis-specified.

### Black keys (switched)

Per supervisor: include the black keys **and make them pressable**, even though
the task never uses them. Geometry mirrors the simulator exactly
(`Piano_Application_vel.py:775`) so the physical board matches the screen:

| Property | Value |
|---|---|
| Count / positions | **7**, between white keys at indices `[0, 2, 3, 5, 6, 7, 9]` |
| Width | 0.58 × key width = **26.1 mm** |
| Length | 0.62 × key length = **86.8 mm**, occupying the **rear** |
| Rise above white key tops | 10 mm (parametric) |
| Function | **switched** — one MX switch each, wired like the white keys |

Indices `2,3,5,6,7` are the real C♯/D♯/F♯/G♯/A♯ of the C–B octave; `0` and `9`
continue the visual pattern across the padding keys, exactly as the sim draws it.

> ✅ **Clearance confirmed.** Black keys fill the rear 86.8 mm, so the fingers
> must contact the white keys within the **front 53.2 mm** (`front_clear`).
> Measured on the rig: the fingertip lands **35 mm** from the front edge — well
> inside the clear zone, so no black key is in the finger's path and no
> repositioning is needed. This sets `contact_x = 35` in the CAD, which also
> fixes where the switch and stop shoulders sit. (The CAD still warns if
> `contact_x` is ever moved into the black-key zone.)

### Black keys are switched, and that reshapes the white keys

Making the black keys pressable forced a change to a part that was otherwise
settled. An **MX switch housing is 15.6 mm across and the gap between white
keys is 5 mm** — the switch is three times too wide to fit, and even a bare
pushrod carrying a keycap mount needs about 6 mm. There is no arrangement that
puts a switch under a black key without widening that gap.

So each white key is **notched by 7.5 mm on the side where a black key sits**,
opening the gap to 20 mm. This is exactly what a real piano does and for the
same reason, so the board also ends up looking more authentic:

| White key | Rear width |
|---|---|
| no black neighbour | 45.0 mm |
| one black neighbour | 37.5 mm |
| two black neighbours | 30.0 mm |

The notch runs from the start of the black key zone to x = 122 mm, stopping
short of the hinge knuckle, which needs its full 45 mm to locate the key on the
pin.

**The black key itself** is a keycap pushed straight onto an MX stem, the way
any keyboard keycap mounts — no hinge, no glue, no separate spring. It travels
straight down while the white keys pivot. That difference is deliberate: a
lever here would collide with the hinge brackets sharing the same gap, and
black keys are never touched by the robot.

**They also need no stop shoulders.** The white keys have them because the
robot presses with 362–520 gf and would otherwise hammer the switch. Black keys
are hand-pressed, so bottoming out at 3.6 mm is ordinary keyboard use, well
inside the switch's 80 M cycle rating.

> ⚠️ **Three clearances are tight and should be checked on the prototype:** the
> socket boss leaves 0.5 mm each side in the widened gap; a fully pressed black
> key clears the hinge posts by 0.9 mm; and the notch ends 0.5 mm before the
> knuckle. All positive, none generous.

## Key → note → pin mapping

**18 keys: 11 white + 7 black.** Key ids run **left → right**, id 0 being the
leftmost key — the end carrying the orientation notch on the board.

White keys use the simulator's own frequencies unchanged
(`Piano_Application_vel.py:753`), so the physical piano and the on-screen one
sound identical.

| id | Key | Note | Hz | Pin |
|---:|:---|:---:|---:|:---:|
| 0  | white 0 (pad) | Bb3 | 233.08 | D2 |
| 1  | white 1 (pad) | B3  | 246.94 | D3 |
| 2  | white 2 | **C4** | 261.63 | D4 |
| 3  | white 3 | **D4** | 293.66 | D5 |
| 4  | white 4 | **E4** | 329.63 | D6 |
| 5  | white 5 | **F4** | 349.23 | D7 |
| 6  | white 6 | **G4** | 392.00 | D8 |
| 7  | white 7 | **A4** | 440.00 | D9 |
| 8  | white 8 | **B4** | 493.88 | D10 |
| 9  | white 9 (pad) | C5 | 523.25 | D11 |
| 10 | white 10 (pad) | Db5 | 554.36 | D12 |
| 11 | black in gap 0/1 | A3 † | 220.00 | A5 |
| 12 | black in gap 2/3 | C♯4 | 277.18 | A0 |
| 13 | black in gap 3/4 | D♯4 | 311.13 | A1 |
| 14 | black in gap 5/6 | F♯4 | 369.99 | A2 |
| 15 | black in gap 6/7 | G♯4 | 415.30 | A3 |
| 16 | black in gap 7/8 | A♯4 | 466.16 | A4 |
| 17 | black in gap 9/10 | D5 † | 587.33 | **D13** |

† Five black keys land on a real sharp. The outer two cannot: the simulator's
padding keys are already a semitone apart (Bb3–B3 and C5–Db5), so no note
exists between them. Those two continue the scale outwards instead. They are
decorative keys the task never presses — change the values freely in
`pc/piano_listener.py`, or set one to `0` to make that key silent.

> **Why D13 carries a padding black key.** On many Uno clones pin 13 drives the
> onboard LED directly, which can load `INPUT_PULLUP` enough to read
> unreliably. It is therefore assigned the least important key, so a flaky pin
> costs nothing that matters. If D13 misbehaves, that one decorative key stops
> working and nothing else changes.

## Wiring

Every switch uses the Arduino's internal pull-up (`INPUT_PULLUP`), so **no
external resistors** and no polarity to get right. Each switch goes between its
pin and GND:

```
   D2 ─────[ white key 0 ]───── GND
   D3 ─────[ white key 1 ]───── GND
    ⋮             ⋮               ⋮
  D12 ─────[ white key 10 ]──── GND
   A5 ─────[ black gap 0/1 ]─── GND
   A0 ─────[ black gap 2/3 ]─── GND
    ⋮             ⋮               ⋮
  D13 ─────[ black gap 9/10 ]── GND     (all commons tie to one GND bus)
```

18 signal wires plus one common ground. A pressed key reads LOW; the firmware
debounces for 15 ms, which clears the switch's 10 ms end-of-life bounce spec.

**There is no speaker on the board.** D13 was the only free pin and it is now a
key — see below.

## Sound: played by the computer

The Arduino is a **pure key scanner**. It reports `P <id>` / `R <id>` over USB
serial and makes no sound; `pc/piano_listener.py` receives those events and
plays the notes.

This is not a workaround. The BCI2000 simulator already plays its notes through
`psychopy.sound`, so PC audio is the existing architecture rather than a
departure from it — and it satisfies "electronic sound, tunable on a computer"
more literally than square waves ever did.

**What it buys us**

- The pin budget closes exactly. 18 switches need all 18 usable pins on an Uno
  (D2–D13 plus A0–A5, with D0/D1 reserved for the serial link). A speaker would
  have needed a 19th.
- Real timbre, polyphony, and any tuning — all in software, no reflashing.
- Simpler firmware: no `tone()`, no frequency table, no EEPROM.

**What it costs**

- The piano cannot make a sound standalone; the PC must be running the
  listener. Since BCI2000 is running during any real use, this is not a
  practical restriction.
- Latency is roughly 15–40 ms end to end (USB serial plus audio buffer). For
  scale, a real piano action takes ~30 ms from key to hammer.

### Running it

```bash
pip install pyserial numpy pygame
python pc/piano_listener.py --test          # play every note, no hardware
python pc/piano_listener.py --port COM5     # normal use
```

`--test` is the quickest way to confirm audio works before any switch is wired.
Add `--echo` to print each key event as it arrives.

The board also answers `ping` (replies `PONG`) and `keys` (lists every id with
its pin) on the same serial port, which is handy for checking wiring one key at
a time with the Arduino IDE's Serial Monitor.

## Bill of materials (buy)

| Qty | Item | Notes |
|----:|---|---|
| 1 | Arduino Uno or Nano | Uno is easiest to prototype; Nano if space-tight |
| 18 (+spares) | **MX-style linear keyboard switches** (~45 gf, 3.6 mm travel) — *chosen* | 11 white + 7 black. Kailh/Cherry linear red. Supplies contact + return spring + travel in one part, so there is **no separate return spring**. 45 gf actuation is far below the weakest finger (362 gf). Standard 14 × 14 mm plate mount. Wire the two switch pins to the Arduino pin/GND |
| ~ | Hookup wire, breadboard or proto-PCB | 18 signal + common GND |
| 1 | USB cable | Power, serial link, and the sound path |

*No speaker, buzzer or amplifier is needed — the computer plays the notes. See
**Sound** above. A piezo is still useful for bench-testing switches before the
PC listener is set up, but it is not part of the finished instrument.*

## Make (3D print / machine shop)

- **Key caps + hinge mechanism (11×, print):** 4.5 cm × 14 cm tops with a
  consistent, repeatable press throw so the robot's fixed flex always closes
  the switch. Printing gives identical keys and lets you tune the throw.
  **Important — protect the switch from overshoot:** the finger drives ~3 cm
  but the switch actuates in ≤ a few mm, so give each key a **hard bottom stop**
  (key cap bottoming against the frame) positioned so the switch actuates *just
  before* the stop. The frame — not the switch internals — then absorbs the
  finger's 362–520 gf overshoot, which is what makes the mechanism durable.
  Parametric CAD implementing all of this (rear pin hinge, plunger, switch
  cradle, stop pads, return spring, up-stop hook) is in
  [`../cad/piano_keys.scad`](../cad/piano_keys.scad) — defaults are self-consistent
  with the measured numbers. **Set `contact_x` and the switch dimensions, then
  print ONE key + base cell to tune before batching 11.**
- **Base / frame (print or machine shop):** holds keys on 5.0 cm centers
  (4.5 cm key + 0.5 cm gap), mounts the switches under each key, and sits at
  the arm's working height. Total ~54.5 cm (21.5″) wide; confirm it fits inside
  the arm's reachable travel before cutting.
  **Must be tiled:** TechSpark's printers have a 254 mm build volume, so the
  545 mm keybed prints as 3 tiles (5 + 4 + 2 cells) and is joined — the CAD's
  `"tile"` mode generates these, one per `tile_i` value. The split avoids
  putting a seam on a black-key boundary, where the joint would cut through a
  switch socket.
- **Black keys (7×, print):** switched keycaps that push straight onto an MX
  stem at the white-key boundaries. Not glued, and not decorative — they are
  wired like the white keys.

## Purchasing & fabrication

- **Parts to buy, with links and budget:** [`PURCHASING.md`](PURCHASING.md)
- **Machine-shop / 3D-print plan (CMU TechSpark):**
  [`TECHSPARK_PLAN.md`](TECHSPARK_PLAN.md)

## Firmware

[`../firmware/piano_firmware.ino`](../firmware/piano_firmware.ino).
Flash with the Arduino IDE. Pitches default to the simulator's frequencies and
are tuned live over serial (see **Sound** above); the serial monitor at 115200
also prints `press N` / `release N` for bring-up testing.

## Press characterization (for switch selection)

The press is **position (PD) control**, not force control (`PressFinger`,
[RockScissorsPaper.cpp:127](../../hand/RockScissorsPaper.cpp)): the knuckle drives
`press_flexion = 0.80` rad and holds for `PRESS_HOLD_MS = 400` ms
([myAllegroHand.cpp:228](../../hand/myAllegroHand.cpp)). Contact force is therefore
emergent (Kp ≈ 800–900 × position error into the surface, up to the torque cap),
so it must be measured, not read from code.

| Spec | Value |
|---|---|
| Fingertip vertical stroke (resting → full press) | **~3 cm (measured, press-and-hold)** |
| Resting fingertip height above table | **~4 cm (measured)** |
| Pressed fingertip height above table | **< 1 cm (measured)** |
| Press force — index (left) finger | **362 g ≈ 3.55 N (measured)** |
| Press force — middle (center) finger | **500 g ≈ 4.90 N (measured)** |
| Press force — ring (right) finger | **520 g ≈ 5.10 N (measured)** |
| **Weakest finger (sets switch spec)** | **index, 362 g ≈ 3.55 N** |

**How measured:** with a zeroed digital scale centered under one fingertip at
key height, each finger was pressed and held using the bench hold mode in the
hand controller (`1`/`2`/`3` = press-and-hold left/center/right, `L` = lift; see
[myAllegroHand.cpp](../../hand/myAllegroHand.cpp) MainLoop), reading the settled
value. `N ≈ g × 0.0098`.

The stroke/height numbers were read off the rig with the finger held in resting
vs. pressed pose (press-and-hold bench mode, not the 400 ms flash). The stroke is
the fingertip's *own* vertical descent, not the depth a key gets depressed.

**Design implications:**
- **Pre-travel is not a constraint.** With ~3 cm of fingertip stroke, any
  switch's actuation travel (sub-mm) fits with room to spare, and the keys can
  have a real, piano-like key-cap travel (~0.5–1 cm) with the switch underneath.
- **Force sets the switch choice.** The switch must fully actuate under the
  *weakest* finger, 362 gf. The chosen MX linear switch actuates at ~45 gf —
  an ~8× margin, so every finger triggers it reliably.
- **The switch must not absorb the overshoot.** MX switches bottom out
  internally at 4 mm, but the finger keeps pushing with 362–520 gf (several
  times a human keystroke). The design therefore drives the stem only 3 mm and
  lands the key cap on **integral stop shoulders** in the socket, leaving 0.6 mm
  of unused switch travel even on a worst-case switch. The frame takes the load, not the
  switch. The CAD warns if these values are ever set inconsistently.

## How the key mechanism works

Each white key is a **rear-hinged lever**, like a real piano key. A small post
(the *plunger*) on its underside rests directly on an MX switch stem:

```
              finger presses here (35 mm from front)
                       ↓
   FRONT ┌─────────────────────────────────────┐ REAR
         │              key lever              │
         └──┬────────┬─────────────────────────┴──○ ← pivot (hinge pin)
            │        │ plunger
          hook     ┌─┴──┐
                   │stem│  ← MX switch: the spring inside pushes UP
                   │▓▓▓▓│    and is what holds the key up
   ════════════════╧════╧════════════════════════  base plate
```

Inside the switch, a spring-loaded stem slides down; a contact closes at ~2 mm
of travel and the spring returns it. **There is no separate return spring** —
the MX spring both holds the key up and returns it.

The hinge pin runs **across** the keyboard so the key pivots up and down. Nothing
else locates the key: the pin holds the rear, and the stem's own top-of-travel
limit sets the resting height (via the plunger length). There is no up-stop
catch — it isn't needed.

### Why the key doesn't press its own switch

The MX spring's guaranteed return force is **15 gf minimum** (datasheet RF), so
nothing moves until something pushes harder than that. The lever geometry then divides the key's weight down:

| | |
|---|---|
| Key mass | 16 g, centre of mass 57 mm from the pivot |
| Plunger position | 92 mm from the pivot |
| Force at the stem | 16 × 57/92 = **9.9 gf** |
| Guaranteed return force (datasheet RF, min) | **15 gf** |
| Maximum safe key mass | **24 g** — ours is 16 g |

By contrast the finger presses at the same 35 mm point, so its full **362 gf**
reaches the stem against a 45 gf requirement — a huge margin the right way.

> ⚠️ **Print the keys at low infill (~20%) — this is now a hard limit.** The
> datasheet guarantees only **15 gf** of return force (RF, minimum), not the
> 30 gf preload previously assumed, so the maximum safe key mass is **24 g**. A
> near-solid key at ~41 g would push 25.4 gf and **would** sag onto its switch
> and self-trigger. At ~20% infill (16 g → 9.9 gf) there is a 1.5× margin. The
> CAD warns if `key_mass_g` exceeds the limit.

### Cut a hole-size test coupon FIRST

The datasheet specifies the plate cutout itself — **14.00 ±0.05 mm square, corners
R0.30 max, in 1.50 ±0.1 mm material** (s.10, "Metal Frame Cutout Dimensions").
The CAD matches that exactly. The problem is not the drawing, it is that
**neither fabrication process naturally holds ±0.05 mm on a 14 mm feature:**

- **FDM undersizes holes**, typically by 0.1–0.4 mm. A nominal 14.00 can come off
  the printer at 13.6–13.9. The switch body is up to 14.00, so it either will not
  go in, or goes in so tightly the clips cannot spring out and latch.
- **Laser cutting oversizes them**, because the kerf (~0.15–0.25 mm) is removed
  from the part. An uncompensated 14.00 vector path yields a ~14.2 hole, and the
  switch rattles instead of clipping.

Both are off in a direction that breaks the joint, and they are off the *opposite*
way, so there is no single number that suits both routes. Before committing to
18 switch positions, cut one coupon carrying holes at **13.8 / 13.9 / 14.0 / 14.1
/ 14.2 / 14.3 / 14.4 mm** in the real material at the real settings, and clip a
real switch into each. Use the smallest hole the switch clips into cleanly and
cannot be pulled out of by hand, then apply that offset to `mx_cut`.

This is a ten-minute job that de-risks the whole board. Getting it wrong is not
recoverable on a printed tile — the hole is in the middle of a 250 mm part.

The corner radius is satisfied by both processes without doing anything: FDM
leaves roughly a nozzle-radius (~0.2 mm) inside corner and a laser leaves a
sharp one, and the spec is a maximum.

### Fitting the switches — order matters

All 18 switches clip in from **above**: the housing lands on the plate, the
13.95 mm neck passes the 1.5 mm plate, and the clips spring out into the 16 mm
relief below (they reach 14.87 mm at full width). The body and pins end 2.6 mm
above the board underside, inside the bore, so they are soldered from below —
the feet leave 12 mm to work in.

**Fit every switch before any key lever goes on.** Once a lever is on the pin
you cannot reach the stop shoulders, and the black-key sockets sit in gaps the
white keys overhang. The order is:

1. join the three tiles (printed route) or bolt up the layer stack (laser route)
2. clip in all 18 switches
3. solder the harness from underneath
4. drop in the 11 levers and thread the hinge rod
5. push the 7 black keycaps onto their stems — last

On the printed route, thread the hinge rod as **three tile-length pieces**, not
one 570 mm rod. A single rod has to pass 23 collinear bores across two glued
seams; per-tile pieces only have to agree within one printed part. (The laser
route can use one rod — every bracket bolts to the same flat sheet.)

## Keyboard height & arm integration

The toy mat modeled key **width and length** well, but as a flat mat (~1 cm above
the table) it does **not** model a real key's **thickness/travel**. A real keyed
instrument will be taller. This is not a problem because the **hand+arm height is
adjustable** — the current mounting height is not fixed. So treat keyboard
thickness as a free design parameter and match the arm height to it:

1. The key/switch/hinge/stop stack is now fixed: key tops sit **42.6 mm**
   above the table (30.6 mm of board on 12 mm feet). Call this **K**.
   (Was 42.2 mm: the pivot rose 0.37 mm when the stop height was corrected —
   see `stop_r_lead` in `piano_params.scad`. The CAD echoes the live figure on
   every render; take **K** from there, not from this line.)
2. Raise the arm so the **resting fingertip hovers ~2–5 mm above the key tops**
   (small positive clearance so a resting finger never holds a key down).
3. The **~3 cm stroke** then presses the key: only ~0.5–1 cm of key throw is
   needed to actuate + bottom out, so `3 cm ≫ clearance + throw` (≈2 cm margin).
   The hard bottom stop absorbs the remaining overshoot.

**To verify before finalizing:** the arm's vertical adjustment range can reach
`K + clearance`. Measured reference points on the current rig: resting fingertip
~4 cm above table, pressed fingertip < 1 cm above table (on the ~1 cm mat).

## Open items

Settled: geometry, sound, press force, the switch spec, and the CAD. Every
figure the model takes from the switch datasheet has been checked against it
line by line.

**Nothing else should be fabricated until the three items below are closed.**
All three need a physical switch in hand, and all three close in one bench
session. **The switches are ordered** (Adafruit #4952 × 2 packs, 20 pcs,
2026-08-04), so the blocking action is now simply *wait for delivery, then do
the bench session*.

1. **Confirm the delivered switch is the switch the CAD was designed to.**
   The order is Adafruit #4952 (Kailh linear red); the datasheet in
   `datasheets/` is Kailh **CPG1511F01S04-1**. Nothing has ever tied those two
   together — the part number on the packaging is the check.

   What does *not* matter: plate-mount vs PCB-mount. The five-pin variant's two
   extra fixation posts sit inside the body footprint, and the bore under the
   plate is a 16 mm open hole in both routes, so either clips in fine.

   What *does* matter: **housing height above the plate**, `mx_housing_h`
   = 5.70 mm. MX-compatible parts agree on the 14 mm cutout and the 15.60 mm
   flange, but this one varies between makers, and it is exactly what gives the
   black keycap its 1.7 mm of free travel before its boss reaches the housing.
   If the part differs, get its datasheet and re-check that number first.

2. **Measure `mx_well_w` and `mx_shoulder_w`** (currently 7.0 and 6.6).
   The datasheet draws the housing opening and the stem top face but never
   dimensions them; both were scaled off the s.5 top view and are ±0.15 mm at
   best. They cap how fat the black keycap's lower boss may be, and if the boss
   does not enter the housing opening the black keys jam ~0.4 mm short of
   actuation. `piano_params.scad` warns if the numbers stop working.

3. **Cut a hole-size test coupon and set `mx_cut` from it.** See "Cut a
   hole-size test coupon FIRST" above. The datasheet's 14.00 ±0.05 is tighter
   than either fabrication process holds, and the two miss it in opposite
   directions. This is the single cheapest way to de-risk 18 switch positions.

Also open, and needed before the base is fabricated (though not before the keys
are):

4. **Choose the route — printed or laser.** They are alternatives; do not build
   both. The laser route cuts all 11 switch positions in one operation, so the
   50 mm pitch the arm is calibrated to has no seams to drift across, and it is
   far cheaper in material. The printed route needs no laser but puts two glued
   joints in that same dimension (the 5 + 4 + 2 tiling keeps both seams off a
   black key) and runs ~500 g of PLA. Needs a TechSpark conversation about
   laser access and 9.0 / 1.5 / 13.0 mm stock.

Then: print **one** cell, one key lever and one black key — `mode = "assembly"`
in `piano_base_printed.scad` is exactly that trio — and check by hand that the
switch clips in, the key pivots on the rod, the cap lands on the stops rather
than the switch, and the black cap grips its cross and travels without fouling
the housing. That exercises every failure mode found so far in one part instead
of thirty. Only then commit to the full run, and to bench-testing firmware +
tuner and integrating under the arm.

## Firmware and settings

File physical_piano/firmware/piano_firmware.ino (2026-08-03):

/*
 * piano_firmware — key scanner for the physical piano
 * ---------------------------------------------------
 * Reads 18 key switches (11 white + 7 black) and reports press/release events
 * over USB serial. It makes NO SOUND: the PC plays the notes, which is how the
 * BCI2000 simulator already works (Piano_Application_vel.py builds
 * psychopy.sound objects). See ../pc/piano_listener.py for the other half.
 *
 * WHY NO PIEZO: an Arduino Uno has 18 usable digital pins once D0/D1 are
 * reserved for the USB serial this sketch depends on. 18 switches need all 18.
 * Driving a speaker as well would need a 19th pin, so sound moved to the PC —
 * which also gets real samples, polyphony and software tuning for free.
 *
 * Board:   Arduino Uno / Nano
 * Sensing: momentary MX switches, each between its pin and GND. INPUT_PULLUP
 *          is used, so NO external resistors. A pressed key reads LOW.
 *          Kailh CPG1511F01S04-1: bounce is 5 ms new / 10 ms end-of-life, so
 *          the 15 ms debounce below has margin over the whole switch life.
 *          The switch needs >= 10 uA wetting current; the internal pull-up
 *          supplies ~167 uA at 5 V, inside its 10 uA .. 10 mA rating.
 *
 * ---- Serial protocol, 115200 baud, newline-terminated ----
 *   out:  P <id>     key pressed
 *         R <id>     key released
 *         READY 18   sent once at boot, with the key count
 *   in :  ping       -> replies PONG
 *         keys       -> lists every id with its pin and label
 *
 * <id> is 0..17:  0-10  = white keys, left to right (0 is the leftmost key,
 *                         matching the simulator and the notch on the board)
 *                11-17  = black keys, left to right
 */

const uint8_t N_WHITE = 11;
const uint8_t N_BLACK = 7;
const uint8_t N_KEYS  = N_WHITE + N_BLACK;   // 18

// White keys, left to right. D2..D12.
const uint8_t WHITE_PIN[N_WHITE] = { 2, 3, 4, 5, 6, 7, 8, 9, 10, 11, 12 };

// Black keys, left to right. These sit in the white-key gaps
// [0,2,3,5,6,7,9] — the same black_idx as piano_params.scad and the simulator.
//
// D13 IS DELIBERATELY LAST. On many Uno clones pin 13 carries the onboard LED
// directly, which can load INPUT_PULLUP enough to read unreliably. It is
// therefore given the RIGHTMOST black key — a decorative padding key the task
// never presses — so if that pin misbehaves nothing important is affected.
const uint8_t BLACK_PIN[N_BLACK] = { A5, A0, A1, A2, A3, A4, 13 };

// Which white-key gap each black key sits in (for the `keys` listing only).
const uint8_t BLACK_GAP[N_BLACK] = { 0, 2, 3, 5, 6, 7, 9 };

const unsigned long DEBOUNCE_MS = 15;

bool          state[N_KEYS];        // debounced: true = pressed
bool          lastRead[N_KEYS];
unsigned long lastChange[N_KEYS];

char    cmd[16];
uint8_t cmdLen = 0;

uint8_t pinFor(uint8_t id) {
  return (id < N_WHITE) ? WHITE_PIN[id] : BLACK_PIN[id - N_WHITE];
}

void setup() {
  for (uint8_t i = 0; i < N_KEYS; i++) {
    pinMode(pinFor(i), INPUT_PULLUP);
    state[i] = lastRead[i] = false;
    lastChange[i] = 0;
  }
  Serial.begin(115200);
  Serial.print(F("READY "));
  Serial.println(N_KEYS);
}

void listKeys() {
  for (uint8_t i = 0; i < N_WHITE; i++) {
    Serial.print(F("  id ")); Serial.print(i);
    Serial.print(F("  pin D")); Serial.print(WHITE_PIN[i]);
    Serial.print(F("  white ")); Serial.println(i);
  }
  for (uint8_t k = 0; k < N_BLACK; k++) {
    Serial.print(F("  id ")); Serial.print(N_WHITE + k);
    Serial.print(F("  pin ")); Serial.print(BLACK_PIN[k]);
    Serial.print(F("  black between white "));
    Serial.print(BLACK_GAP[k]); Serial.print('/');
    Serial.println(BLACK_GAP[k] + 1);
  }
}

void pollSerial() {
  while (Serial.available()) {
    char c = Serial.read();
    if (c == '\n' || c == '\r') {
      if (cmdLen) {
        cmd[cmdLen] = '\0';
        if      (!strcasecmp(cmd, "ping")) Serial.println(F("PONG"));
        else if (!strcasecmp(cmd, "keys")) listKeys();
        cmdLen = 0;
      }
    } else if (cmdLen < sizeof(cmd) - 1) {
      cmd[cmdLen++] = c;
    }
  }
}

void loop() {
  pollSerial();

  unsigned long now = millis();
  for (uint8_t i = 0; i < N_KEYS; i++) {
    bool reading = (digitalRead(pinFor(i)) == LOW);   // pressed == LOW

    if (reading != lastRead[i]) {
      lastRead[i]   = reading;
      lastChange[i] = now;
    }
    if ((now - lastChange[i]) >= DEBOUNCE_MS && reading != state[i]) {
      state[i] = reading;
      Serial.print(state[i] ? F("P ") : F("R "));
      Serial.println(i);
    }
  }
}

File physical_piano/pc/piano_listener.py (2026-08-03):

#!/usr/bin/env python3
"""
piano_listener.py — plays the physical piano's notes on the computer.

The Arduino is only a key scanner: it reports `P <id>` / `R <id>` over USB
serial and makes no sound of its own. This script turns those events into
audio. That split exists because 18 switches use every usable pin on an Uno,
leaving none for a speaker — and it matches the BCI2000 simulator, which
already plays its notes through psychopy.sound.

Requires: pyserial, numpy, and pygame  ->  pip install pyserial numpy pygame

Examples
--------
  python piano_listener.py --port COM5        # normal use
  python piano_listener.py --test             # play every note, no hardware
  python piano_listener.py --port COM5 --echo # also print each event
"""

import argparse
import sys
import time

try:
    import numpy as np
except ImportError:
    sys.exit("numpy is required:  pip install numpy")

N_WHITE, N_BLACK = 11, 7
N_KEYS = N_WHITE + N_BLACK

# ---------------------------------------------------------------- notes ----
# White keys are the simulator's own table, unchanged
# (Piano_Application_vel.py:753) so the physical piano and the on-screen one
# sound identical.
WHITE_HZ = [233.08, 246.94, 261.63, 293.66, 329.63,
            349.23, 392.00, 440.00, 493.88, 523.25, 554.36]
WHITE_NAME = ["Bb3", "B3", "C4", "D4", "E4", "F4", "G4", "A4", "B4", "C5", "Db5"]

# Black keys sit in the white-key gaps [0,2,3,5,6,7,9]. Five of them land on a
# real sharp. The outer two do not: the simulator's padding keys are already a
# semitone apart (Bb3-B3 and C5-Db5), so there is no note between them. Those
# two continue the scale outwards instead — they are decorative keys the task
# never presses, so change these freely if the supervisor prefers other values
# (setting one to 0 makes that key silent).
BLACK_GAP  = [0, 2, 3, 5, 6, 7, 9]
BLACK_HZ   = [220.00, 277.18, 311.13, 369.99, 415.30, 466.16, 587.33]
BLACK_NAME = ["A3*", "C#4", "D#4", "F#4", "G#4", "A#4", "D5*"]

NOTE_HZ   = WHITE_HZ + BLACK_HZ
NOTE_NAME = WHITE_NAME + BLACK_NAME


def label(key_id):
    if key_id < N_WHITE:
        return f"white {key_id} ({NOTE_NAME[key_id]})"
    k = key_id - N_WHITE
    return f"black {BLACK_GAP[k]}/{BLACK_GAP[k]+1} ({NOTE_NAME[key_id]})"


# ---------------------------------------------------------------- audio ----
SAMPLE_RATE = 44100


def render(freq, seconds=2.5):
    """One note as a stereo int16 buffer.

    A plain sine sounds thin and clicks on release, so this adds a couple of
    quiet harmonics and an attack/decay envelope — closer to a struck string
    and, more practically, free of clicks at note boundaries.
    """
    if freq <= 0:
        return np.zeros((int(SAMPLE_RATE * 0.05), 2), dtype=np.int16)
    t = np.linspace(0, seconds, int(SAMPLE_RATE * seconds), endpoint=False)
    wave = (np.sin(2 * np.pi * freq * t)
            + 0.25 * np.sin(2 * np.pi * 2 * freq * t)
            + 0.12 * np.sin(2 * np.pi * 3 * freq * t))
    attack = np.clip(t / 0.006, 0, 1)          # ~6 ms, avoids a click
    decay = np.exp(-t * 1.6)
    wave *= attack * decay
    wave /= np.max(np.abs(wave)) or 1.0
    mono = (wave * 0.28 * 32767).astype(np.int16)
    return np.column_stack([mono, mono])


class Audio:
    """pygame.mixer wrapper. It gives polyphony for free, which the Arduino's
    tone() never could — overlapping notes just work."""

    def __init__(self):
        import pygame
        self.pygame = pygame
        # 512-frame buffer keeps output latency near 12 ms; the whole chain
        # then lands in the same range as a real piano action (~30 ms).
        pygame.mixer.pre_init(SAMPLE_RATE, -16, 2, 512)
        pygame.mixer.init()
        pygame.mixer.set_num_channels(N_KEYS + 4)
        self.sounds = [pygame.sndarray.make_sound(render(f)) for f in NOTE_HZ]
        self.channels = {}

    def press(self, key_id):
        ch = self.sounds[key_id].play()
        if ch:
            self.channels[key_id] = ch

    def release(self, key_id):
        ch = self.channels.pop(key_id, None)
        if ch:
            ch.fadeout(140)        # stands in for a piano damper

    def close(self):
        self.pygame.mixer.quit()


# ---------------------------------------------------------------- main -----
def run_test(audio):
    print("Playing every note. White keys first, then black.\n")
    for i in range(N_KEYS):
        print(f"  {i:2d}  {label(i)}")
        audio.press(i)
        time.sleep(0.45)
        audio.release(i)
        time.sleep(0.05)
    time.sleep(0.5)


def run_serial(audio, port, baud, echo):
    try:
        import serial
    except ImportError:
        sys.exit("pyserial is required:  pip install pyserial")

    with serial.Serial(port, baud, timeout=0.05) as ser:
        time.sleep(2)                     # the board resets when the port opens
        ser.reset_input_buffer()
        print(f"Listening on {port}. Ctrl-C to stop.\n")
        buf = ""
        while True:
            data = ser.read(256).decode("ascii", errors="replace")
            if data:
                buf += data
                while "\n" in buf:
                    line, buf = buf.split("\n", 1)
                    handle(line.strip(), audio, echo)
            else:
                time.sleep(0.001)


def handle(line, audio, echo):
    if not line:
        return
    parts = line.split()
    if len(parts) == 2 and parts[0] in ("P", "R"):
        try:
            key_id = int(parts[1])
        except ValueError:
            return
        if not 0 <= key_id < N_KEYS:
            print(f"  ignoring out-of-range key id {key_id}")
            return
        if parts[0] == "P":
            audio.press(key_id)
            if echo:
                print(f"  press   {label(key_id)}")
        else:
            audio.release(key_id)
            if echo:
                print(f"  release {label(key_id)}")
    else:
        print(f"  [board] {line}")       # READY, PONG, key listings


def main():
    ap = argparse.ArgumentParser(description=__doc__,
                                 formatter_class=argparse.RawDescriptionHelpFormatter)
    ap.add_argument("--port", help="serial port, e.g. COM5 or /dev/ttyUSB0")
    ap.add_argument("--baud", type=int, default=115200)
    ap.add_argument("--test", action="store_true",
                    help="play every note once and exit — no board needed")
    ap.add_argument("--echo", action="store_true", help="print each key event")
    args = ap.parse_args()

    if not args.test and not args.port:
        ap.error("give --port, or --test to check audio without the board")

    try:
        audio = Audio()
    except ImportError:
        sys.exit("pygame is required:  pip install pygame")

    try:
        if args.test:
            run_test(audio)
        else:
            run_serial(audio, args.port, args.baud, args.echo)
    except KeyboardInterrupt:
        print("\nstopped")
    finally:
        audio.close()


if __name__ == "__main__":
    main()

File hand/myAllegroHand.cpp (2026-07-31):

// myAllegroHand.cpp : Defines the entry point for the console application.
//

#include <winsock2.h>
#include <ws2tcpip.h>
#pragma comment(lib, "ws2_32.lib")
#include "stdafx.h"
#include "windows.h"
#include <conio.h>
#include <process.h>
#include <tchar.h>
#include "canAPI.h"
#include "rDeviceAllegroHandCANDef.h"
#include "rPanelManipulatorCmdUtil.h"
#include "BHand/BHand.h"

/////////////////////////////////////////////////////////////////////////////////////////
/////////////////////////////////////////////////////////////////////////////////////////
// IMPORTANT !!
// SET CORRECT HAND PARAMETER HERE BEFORE RUNNING THIS PROGRAM.
const bool	RIGHT_HAND = true;
const int	HAND_VERSION = 4;
/////////////////////////////////////////////////////////////////////////////////////////
/////////////////////////////////////////////////////////////////////////////////////////

/////////////////////////////////////////////////////////////////////////////////////////
// for CAN communication
const double delT = 0.003;
int CAN_Ch = 0;
bool ioThreadRun = false;
uintptr_t ioThread = 0;
int recvNum = 0;
int sendNum = 0;
double statTime = -1.0;
AllegroHand_DeviceMemory_t vars;

/////////////////////////////////////////////////////////////////////////////////////////
// for rPanelManipulator
rPanelManipulatorData_t* pSHM = NULL;
double curTime = 0.0;

/////////////////////////////////////////////////////////////////////////////////////////
// for BHand library
BHand* pBHand = NULL;
double q[MAX_DOF];
double q_des[MAX_DOF];
double tau_des[MAX_DOF];
double cur_des[MAX_DOF];

/////////////////////////////////////////////////////////////////////////////////////////
// Hand parameters
const double tau_cov_const_v4 = 1200.0; // 1200.0 for SAH040xxxxx
const short pwm_max_DC8V = 800; // 1200 is max
const short pwm_max_DC24V = 500;

/////////////////////////////////////////////////////////////////////////////////////////
// sample motions
#include "RockScissorsPaper.h"

/////////////////////////////////////////////////////////////////////////////////////////
// functions declarations
void PrintInstruction();
void MainLoop();
bool OpenCAN();
void CloseCAN();
int GetCANChannelIndex(const TCHAR* cname);
bool CreateBHandAlgorithm();
void DestroyBHandAlgorithm();
void ComputeTorque();

/////////////////////////////////////////////////////////////////////////////////////////
// CAN communication thread
static unsigned int __stdcall ioThreadProc(void* inst)
{
	int id;
	int len;
	unsigned char data[8];
	unsigned char data_return = 0;
	int i;

	while (ioThreadRun)
	{
		/* wait for the event */
		while (0 == get_message(CAN_Ch, &id, &len, data, FALSE))
		{
			//            printf(">CAN(%d): ", CAN_Ch);
			//            for(int nd=0; nd<len; nd++)
			//                printf("%02x ", data[nd]);
			//            printf("\n");

			switch (id)
			{
			case ID_RTR_HAND_INFO:
			{
				printf(">CAN(%d): AllegroHand hardware version: 0x%02x%02x\n", CAN_Ch, data[1], data[0]);
				printf("                      firmware version: 0x%02x%02x\n", data[3], data[2]);
				printf("                      hardware type: %d(%s)\n", data[4], (data[4] == 0 ? "right" : "left"));
				printf("                      temperature: %d (celsius)\n", data[5]);
				printf("                      status: 0x%02x\n", data[6]);
				printf("                      servo status: %s\n", (data[6] & 0x01 ? "ON" : "OFF"));
				printf("                      high temperature fault: %s\n", (data[6] & 0x02 ? "ON" : "OFF"));
				printf("                      internal communication fault: %s\n", (data[6] & 0x04 ? "ON" : "OFF"));
			}
			break;
			case ID_RTR_SERIAL:
			{
				printf(">CAN(%d): AllegroHand serial number: SAH0%d0 %c%c%c%c%c%c%c%c\n", CAN_Ch, HAND_VERSION
					, data[0], data[1], data[2], data[3], data[4], data[5], data[6], data[7]);
			}
			break;
			case ID_RTR_FINGER_POSE_1:
			case ID_RTR_FINGER_POSE_2:
			case ID_RTR_FINGER_POSE_3:
			case ID_RTR_FINGER_POSE_4:
			{
				int findex = (id & 0x00000007);

				vars.enc_actual[findex * 4 + 0] = (short)(data[0] | (data[1] << 8));
				vars.enc_actual[findex * 4 + 1] = (short)(data[2] | (data[3] << 8));
				vars.enc_actual[findex * 4 + 2] = (short)(data[4] | (data[5] << 8));
				vars.enc_actual[findex * 4 + 3] = (short)(data[6] | (data[7] << 8));
				data_return |= (0x01 << (findex));
				recvNum++;

				//                printf(">CAN(%d): Encoder[%d] Count : %6d %6d %6d %6d\n"
				//                    , CAN_Ch, findex
				//                    , vars.enc_actual[findex*4 + 0], vars.enc_actual[findex*4 + 1]
				//                    , vars.enc_actual[findex*4 + 2], vars.enc_actual[findex*4 + 3]);

				if (data_return == (0x01 | 0x02 | 0x04 | 0x08))
				{
					// convert encoder count to joint angle
					for (i = 0; i<MAX_DOF; i++)
					{
						q[i] = (double)(vars.enc_actual[i])*(333.3 / 65536.0)*(3.141592 / 180.0);
					}

					// print joint angles
					//                    for (int i=0; i<4; i++)
					//                    {
					//                        printf(">CAN(%d): Joint[%d] Pos : %5.1f %5.1f %5.1f %5.1f\n"
					//                            , CAN_Ch, i, q[i*4+0]*RAD2DEG, q[i*4+1]*RAD2DEG, q[i*4+2]*RAD2DEG, q[i*4+3]*RAD2DEG);
					//                    }

					// compute joint torque
					ComputeTorque();

					// convert desired torque to desired current and PWM count
					for (int i = 0; i<MAX_DOF; i++)
					{
						cur_des[i] = tau_des[i];
						if (cur_des[i] > 1.0) cur_des[i] = 1.0;
						else if (cur_des[i] < -1.0) cur_des[i] = -1.0;
					}

					// send torques
					for (int i = 0; i<4; i++)
					{
						vars.pwm_demand[i * 4 + 0] = (short)(cur_des[i * 4 + 0] * tau_cov_const_v4);
						vars.pwm_demand[i * 4 + 1] = (short)(cur_des[i * 4 + 1] * tau_cov_const_v4);
						vars.pwm_demand[i * 4 + 2] = (short)(cur_des[i * 4 + 2] * tau_cov_const_v4);
						vars.pwm_demand[i * 4 + 3] = (short)(cur_des[i * 4 + 3] * tau_cov_const_v4);

						command_set_torque(CAN_Ch, i, &vars.pwm_demand[4 * i]);
						//for (int k = 0; k<100000; k++);
						//usleep(5);
					}
					sendNum++;
					curTime += delT;
					data_return = 0;
				}
			}
			break;
			case ID_RTR_IMU_DATA:
			{
				printf(">CAN(%d): AHRS Roll : 0x%02x%02x\n", CAN_Ch, data[0], data[1]);
				printf("               Pitch: 0x%02x%02x\n", data[2], data[3]);
				printf("               Yaw  : 0x%02x%02x\n", data[4], data[5]);
			}
			break;
			case ID_RTR_TEMPERATURE_1:
			case ID_RTR_TEMPERATURE_2:
			case ID_RTR_TEMPERATURE_3:
			case ID_RTR_TEMPERATURE_4:
			{
				int sindex = (id & 0x00000007);
				int celsius = (int)(data[0]) |
					(int)(data[1] << 8) |
					(int)(data[2] << 16) |
					(int)(data[3] << 24);
				printf(">CAN(%d): Temperature[%d]: %d (celsius)\n", CAN_Ch, sindex, celsius);
			}
			break;
			default:
				printf(">CAN(%d): unknown command %d, len %d\n", CAN_Ch, id, len);
				/*for(int nd=0; nd<len; nd++)
				printf("%d \n ", data[nd]);*/
				//return;
			}
		}
	}
	return NULL;
}
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

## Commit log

2026-07-21 Add Piano Task Files
    Need to adapt arm+hand controllers to handle this new signal format
2026-07-24 Update arm home pose to match physical setup snapshot
    Set HOME_X/Y/Z and thetas from the measured end-effector pose
    captured from the Kinova monitoring snapshot (2026-07-24).
2026-07-24 Fix arm servo axis, gain, and direction for new home pose
    The home-pose change exposed several latent bugs in the 1-D key servo,
    found and validated on the physical rig:
    - Track world X (base frame), not world Y. The old code sent a tool-frame
    linear_x twist that only aligned with the key row when HOME_THETA_Z was
    90 deg; the new home orientation made the arm drive along the wrong axis
    and never converge (runaway).
    - Replace the deadbeat vel = error/LOOP_TIME with a proportional gain
    (KP = 3.0) to stop overshoot/oscillation near the target.
    - Flip ARM_Y_SIGN to -1 so higher key indices track toward the right hand's
    ring-finger side (finger 2 presses key index+1).
    - Re-home to the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
2026-07-24 Add piano key-press motion to hand controller
    - PressFinger now drives the press from the proximal (MCP) knuckle joint,
    with the resting posture (initpos) set so fingertips point straight down;
    the three playing fingers share one identical, tunable posture.
    - Tune press_flexion for full key depression on the physical rig.
    - Widen the simulator's FingerMovePhase pulse to ~3 packets so the rising
    edge is never missed at 8 Hz.
    - Lower arm HOME_Z to bring the hand closer to the keyboard.
    - Document the proximal-joint press model in the setup guide.
2026-07-24 Raise ResultHoldTime to 375ms in piano parameter file
    At 8 Hz (125 ms/packet) the previous 100 ms FingerMovePhase hold was
    shorter than one packet and could be missed entirely; 375 ms (~3 packets)
    guarantees the rising edge reaches the hand controller. Matches the value
    validated in a live BCI2000 dry run.
2026-07-31 Add bench press-and-hold mode to hand controller
    Keys 1/2/3 press and hold the left/center/right finger; L lifts back to
    the resting pose. The normal task press auto-lifts after PRESS_HOLD_MS
    (400 ms), which is too brief for a scale to settle, so the contact force
    could not be measured.
    Used to measure the per-finger press force against a digital scale:
    362 gf (index), 500 gf (middle), 520 gf (ring). Those numbers set the
    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
2026-07-31 Add physical piano design: CAD, firmware, tuner, and specs
    Replaces the toy playmat with a real 11-key instrument. Every dimension
    is measured off the rig or taken from the switch datasheet.
    Geometry (measured): 11 white keys 45 x 140 mm on a 50 mm pitch, which is
    what the arm is calibrated to, plus 7 decorative black keys mirroring the
    BCI2000 simulator's proportions. Fingertip contact lands 35 mm from the
    key's front edge, inside the black keys' 53.2 mm clear zone.
    Switches are MX-style linear, verified against the Kailh CPG1511F01S04-1
    datasheet (included). The datasheet corrected three assumptions: travel
    is 3.6 mm not 4.0, actuation 1.8 mm not 2.0, and guaranteed return force
    is 15 gf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
    [piano_base_laser.scad, piano_base_printed.scad, piano_keys.scad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]
2026-08-03 Move sound to the computer; Arduino becomes a key scanner
    Making the black keys pressable takes the switch count to 18, which is
    exactly the number of usable digital pins on an Uno once D0/D1 are
    reserved for USB serial. A speaker would have needed a 19th.
    Moving audio to the PC frees that pin and is the better design anyway:
    the BCI2000 simulator already plays its notes through psychopy.sound, so
    this matches the existing architecture rather than departing from it, and
    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
2026-08-03 Switched black keys, notched white keys, and fix board orientation
    Black keys become pressable, which forces a change to the white keys. An
    MX housing is 15.6 mm across and the gap between white keys is 5 mm, so
    no switch can sit under a black key until that gap widens. Each white key
    is therefore notched 7.5 mm on its black-key side, opening the gap to
    20 mm. This is what a real piano does and for the same reason. The notch
    stops at x=122 so the hinge knuckle keeps the full width it needs to stop
    the key sliding along the pin.
    The black key itself is now a keycap pushed onto an MX stem, travelling
    straight down while the white keys pivot. A lever would have collided
    with the hinge brackets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
    [piano_base_laser.scad, piano_base_printed.scad, piano_keys.scad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]
2026-08-03 Add cosmetic frame
    Two end cheeks plus front and back rails, 558 x 153 x 56 mm. Purely
    aesthetic per the supervisor's request: it carries no load and holds no
    switch, so it can be printed last or skipped without touching anything
    else. It does usefully hide the 12 mm wiring gap under the board.
    The clearance rule drives the shape. The robot's fingers come down from
    above and land 35 mm back from the key front, so nothing may sit above
    white-key height in that zone. The front rail therefore stands entirely
    ahead of the keys and tops out flush with them; the cheeks and back rail
    are clear of the fingers and rise above the black keys. The file warns if
    the front rail is ever raised past the wh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
    [piano_frame.scad]
2026-08-03 Update docs for PC audio, switched black keys and the frame
    Covers this round of design changes: 18 switches and their pin map, the
    no-speaker wiring, why the white keys are notched, the parts manifest
    gaining the frame, and the printed route's integral feet replacing bought
    standoffs on that route.
    Figures re-synced across every document: printed route 502 g / $321,
    grand total ~$457, 2 spare switches of the 20 ordered rather than 9.
    Also fixes the markdown-to-docx converter, which was silently dropping
    backslash-escaped characters. The first attempt made it worse by leaving
    the escaped asterisk in place with a marker beside it, so the italic rule
    paired the two surviving asterisks and at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
2026-08-04 Fix switch fit and press geometry; add a to-scale switch model
    Verifying the switch mounts against the Kailh datasheet (KH-PS1706-10 rev B
    p.3) turned up several faults. None of them were visible from the parameters
    alone, because nothing in the project drew the switch.
    Blocking:
    * Black keycap gripped nothing. The cross socket was cut UPWARD from
    stem_top_z, but the cross occupies the 3.80 mm BELOW that. The socket sat
    entirely above the stem and the cap would have lifted straight off. The post
    now starts at the cross base (shoulder_z) and seats on the stem shoulder.
    * Black keycap post was one full-width block, so once the socket was lowered
    it grounded on the housing after 1.7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
    [mx_switch.scad, piano_base_laser.scad, piano_base_printed.scad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]
2026-08-04 Centre the black key stem under its cap; drop dead web params
    blk_switch_x was 75: 21.8 mm behind the black cap's front edge but 65 mm ahead
    of its back. The single MX stem is the cap's only support, so that had two
    consequences. The cap's own weight acted ~22 mm behind the stem, biasing the
    key nose-up under nothing but gravity. And a press on the back end applied
    three times the moment of a press on the front, into a stem with no stabiliser.
    Now derived as key_len - black_len/2 = 96.6, the cap's centroid: the static
    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
    [mx_switch.scad, piano_base_printed.scad, piano_params.scad]
2026-08-04 Audit every switch parameter against the datasheet
    Went through all 12 pages rather than the profile drawing alone. Every value
    the model takes from the datasheet is correct — TT 3.60+/-0.3, PT 1.80+/-0.3,
    OF 45+/-10, RF 15 min, and the whole s.5 profile. Two things improved the
    sourcing and three gaps turned up.
    Stronger than before: s.10 "Metal Frame Cutout Dimensions" specifies the PLATE
    HOLE directly — 14.00 +/-0.05 square, R0.30 max corners, 1.50 +/-0.1 material.
    mx_cut and mx_plate_th were inferred from the body width; they now cite the
    manufacturer's own plate spec, and the two agree exactly.
    Gaps closed:
    * OT (overtravel, 1.30 min) was not carried at all. It matters more than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
    [piano_base_printed.scad, piano_params.scad]
2026-08-04 Docs: replace the stale "no blockers" status with the real ones
    BUILD.md's Open items said "(none blocking)". That was true before the switch
    audit and is not now — the first thing anyone picking this up would read is
    that there is nothing in the way, immediately before printing 30 parts.
    Open items now lists the three things that cannot be settled on paper, all of
    which need a physical switch and all of which close in one bench session, so
    the blocking action is stated plainly: order the switches.
    1. confirm the purchased switch matches the datasheet the CAD was designed
    to (BOM points at Adafruit #4952; datasheet in the repo is Kailh
    CPG1511F01S04-1, and housing height abov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
2026-08-04 Record the placed order; fix two BOM notes that would misbuild the piano
    Supervisor placed the order 2026-08-04. Recorded in PURCHASING.md against the
    highlighted rows of Physical_Piano_BOM.docx, and BUILD.md's open items no
    longer say "order the switches" — they are ordered, so the gate is delivery.
    Checking the ordered list against the CAD turned up two notes that were wrong
    in a way that would have been followed:
    * The CA glue was listed as "gluing black keys into locating grooves". Black
    keys stopped being glued risers some time ago — they are keycaps that push
    onto a switch stem and have to come off again for servicing. Someone working
    from the BOM would have glued seven key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
2026-08-04 Add the switch-hole test coupon; correct the laser bed size we ask for
    switch_fit_coupon.scad is new and is the first thing that should be made in
    either process. It carries seven sockets at 13.8-14.4 mm in 0.1 steps, with
    the real 1.5 mm plate and a 5 mm clip relief under it, so the clips open and
    latch exactly as they will in the finished part — a blind plate would test
    nothing. Sizes are engraved and the small-hole end is notched, so a coupon
    turned round on the bench still reads correctly.
    Two modes: "printed" (STL) and "2d_laser" (DXF, cut in the same 1.5 mm stock
    as the real switch plate, since kerf depends on material and thickness).
    It deliberately repeats the socket stack rather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
    [switch_fit_coupon.scad]
2026-08-06 Commit the TechSpark export set so any machine can clone and go
    Generated STL/DXF for every part, plus a README explaining what to make first
    and what each file is for. These are build artifacts and the .scad files remain
    the source of truth, but committing them means a laptop taken to the consult —
    or TechSpark's own PC — gets a working set from one clone, with no OpenSCAD
    install and no file-by-file transfer.
    The README leads with the two coupon files, since nothing else should be cut in
    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
    [COUPON_laser_switch_holes_1.5mm.dxf, COUPON_print_switch_holes.stl, LASER_1_structure_9.0mm.dxf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]
2026-08-06 Fix the tolerance question: there is no sliding plunger
    Consult question 1 asked about "a pin hinge and a sliding plunger with 0.4 mm
    clearances". The plunger slides in nothing. It is a free-standing 4 mm post
    that presses on the switch stem, with 6.5 mm of air either side of it — the
    wording dates from a design where it ran in a guide bore. Asked that way at the
    consult it would have drawn advice about a part that does not exist, and this
    is the first question on the list.
    Replaced with the two moving fits that are actually in the design, both 0.4 mm:
    key side to hinge post 0.4 mm gap (clr)
    pin bore to 3 mm rod 3.4 mm bore, 0.2 mm radial — the real bearing
    Also worth sayin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
